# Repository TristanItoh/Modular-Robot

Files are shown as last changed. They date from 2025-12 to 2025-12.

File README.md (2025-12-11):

# Wireless Snap-On Modular Robot
A wheeled robot with a module slot on the front, allowing module attachments wirelessly through pogo pins. Driven by two motors in the rear and controlled by a joystick mounted on top.

## Why?
I've previously made a robot that is sort of modular, but you need to connect the wires together and use the janky pins to attach them to the base. I wanted to create a new robot with an improved system completely wireless.

## PCB: 
Includes:
- Power management
- Motor driver
- Wireless module interface (pogo pins)
- Microcontroller hub
- Headlights module
  


### Schematic


## CAD: 
Smooth, round base with a flat front for module additions. Detachable lid for battery and PCB.






Simple shell for the headlights module to be contained in.



Simple lightweight wheels with slots for motor shaft.



<br>

## BOM
| Item | Type | Quantity | Price (Total) | Vendor |
|:---|:---|---:|:---|:---|
| CL21A106KAYNNNE | 10uF | 10 | $0.10 | JLCPCB |
| CL31A226KAHNNNE | 22uF | 5 | $0.20 | JLCPCB |
| CL21B105KBFNNNE | 1uF | 5 | $0.04 | JLCPCB |
| CL10A225KO8NNNC | 2.2uF | 10 | $0.05 | JLCPCB |
| CL31A107MQHNNNE | 100uF | 5 | $0.27 | JLCPCB |
| CL05B104KO5NNNC | 100nF | 20 | $0.02 | JLCPCB |
| CL21B103KBANNNC | 10nF | 5 | $0.03 | JLCPCB |
| B2B-XH-A(LF)(SN) | JSTConnector | 20 | $0.70 | LCSC |
| XL-302UWC | XL-302UWC | 20 | $0.46 | LCSC |
| KT-0603R | KT-0603R | 5 | $0.03 | JLCPCB |
| AO3401A | AO3401A | 5 | $0.28 | JLCPCB |
| 0603WAF5101T5E | 5.1kΩ | 10 | $0.01 | JLCPCB |
| 0603WAF1201T5E | 1.2kΩ | 5 | $0.01 | JLCPCB |
| 0603WAF3303T5E | 330kΩ | 5 | $0.01 | JLCPCB |
| 1206W4F1003T5E | 100kΩ | 5 | $0.02 | JLCPCB |
| 0805W8F1002T5E | 10kΩ | 20 | $0.04 | JLCPCB |
| 0805W8F1000T5E | 100Ω | 10 | $0.02 | JLCPCB |
| 0805W8F2200T5E | 220Ω | 15 | $0.03 | JLCPCB |
| TS-1088-AR02016 | TS-1088-AR02016 | 15 | $0.64 | JLCPCB |
| ESP32-S3-WROOM-1-N8R2 | 2.4GHz | 0 | $4.69 | LCSC |
| TP4056 | TP4056 | 0 | $0.42 | LCSC |
| TPS61202DRCT | TPS61202DRCT | 0 | $1.76 | LCSC |
| APH0420T4R7M | 4.7uH | 0 | $0.41 | LCSC |
| AP2112K-3.3TRG1 | AP2112K-3.3TRG1 | 0 | $0.46 | LCSC |
| DRV8833PWPR | DRV8833PWPR | 0 | $0.67 | LCSC |
| TYPE-C 16PIN 2MD(073) | TYPE-C16PIN2MD(073) | 10 | $0.59 | LCSC |
| 1206L150/16NR | 1206L150/16NR | 10 | $0.46 | LCSC |
| Xinyangze YZ134112062B-02 | Pogo pins | 5 | $1.43 | LCSC |
| Joystick module | nan | 1 | 1.2 | Aliexpress |
| Gear motor | N20 | 10 | 7 | Aliexpress |
| PCB + PCBA + other fees | nan | nan | $14.86 | JLCPCB |
| Shipping and handling | nan | nan | $11.62 | LCSC |
| Shipping | nan | nan | $1.99 | Aliexpress |

Total: $50.50

[Sheet With Links](https://docs.google.com/spreadsheets/d/1DUcNddXo8VYgS7BtmotNU0K7JUAEApslePg6cg7R3zo/edit?usp=sharing)

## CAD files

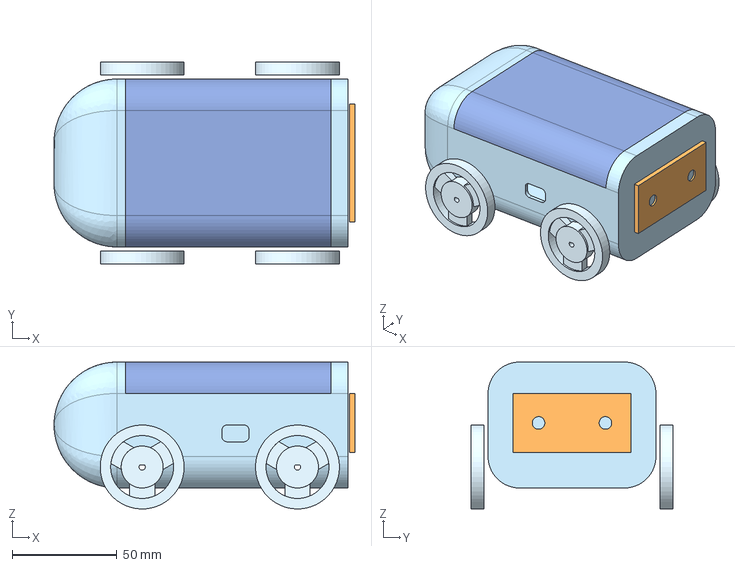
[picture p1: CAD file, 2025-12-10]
CAD/Full robot.step
143.4 x 96.0 x 70.0 mm

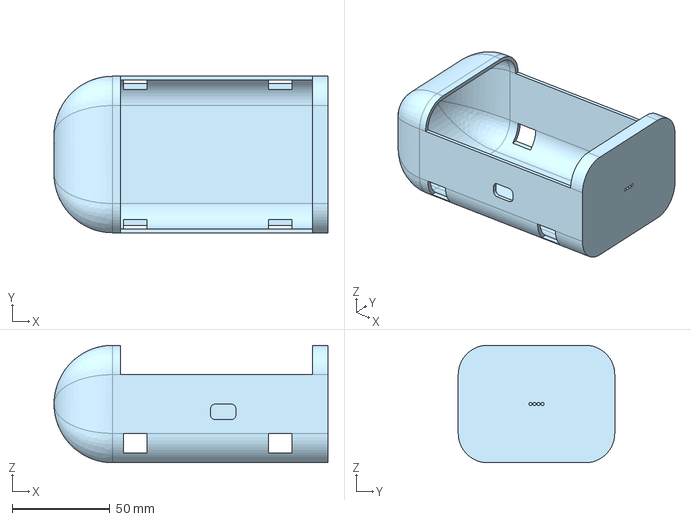
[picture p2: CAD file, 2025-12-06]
CAD/Body.step
140.0 x 80.0 x 60.0 mm

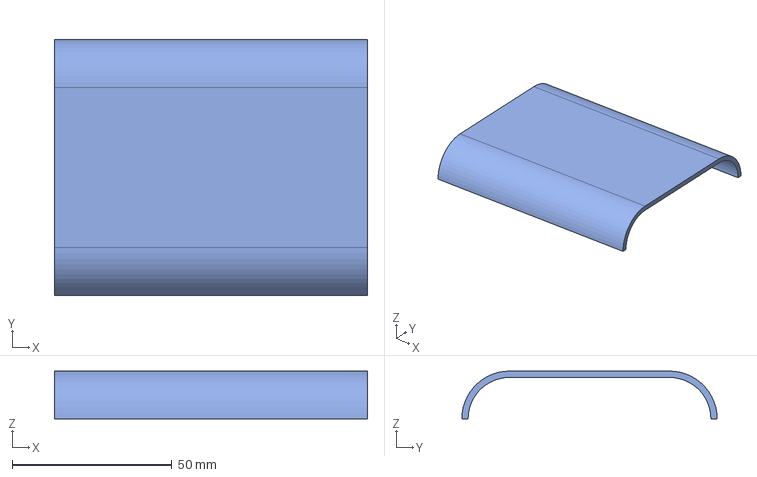
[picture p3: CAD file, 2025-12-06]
CAD/Body Lid.step
98.0 x 80.0 x 15.0 mm

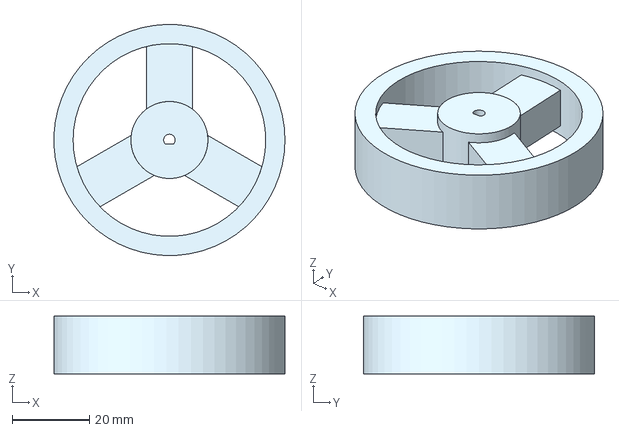
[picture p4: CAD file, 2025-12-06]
CAD/Wheel.step
60.0 x 60.0 x 15.0 mm

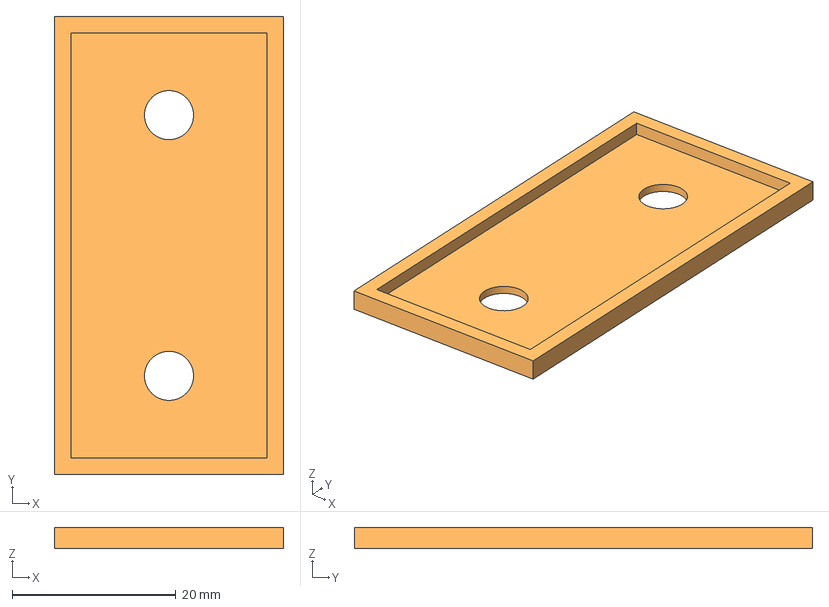
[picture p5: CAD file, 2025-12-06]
CAD/Headlights Body.step
28.0 x 56.0 x 2.60 mm

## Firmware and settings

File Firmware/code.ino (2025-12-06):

/*
 * ESP32-S3 Modular Robot Base Firmware
 * 
 * Hardware:
 * - ESP32-S3 WROOM module
 * - DRV8833 dual motor driver
 * - Analog joystick (X, Y, SW)
 * - Headlight module (LED control via GPIO)
 * - 3 buttons: RESET, BOOT, USER
 * - Status LED
 * 
 * Controls:
 * - Joystick X/Y: Tank-style motor control
 * - Joystick button press: Toggle headlights
 * - User button: Emergency motor stop
 */

// ===== PIN DEFINITIONS =====

// Motor Driver (DRV8833)
#define MOTOR_AIN1  6   // Left motor direction 1
#define MOTOR_AIN2  7   // Left motor direction 2
#define MOTOR_BIN1  15  // Right motor direction 1
#define MOTOR_BIN2  16  // Right motor direction 2

// PWM channels for motor control
#define PWM_FREQ    20000  // 20kHz PWM frequency
#define PWM_RES     8      // 8-bit resolution (0-255)
#define PWM_CH_A1   0
#define PWM_CH_A2   1
#define PWM_CH_B1   2
#define PWM_CH_B2   3

// Headlight Module (Pogo Pin)
#define LED_CTRL    5   // Headlight control GPIO
#define EXTRA_GPIO  4   // Extra GPIO (unused)

// Joystick (analog + button)
#define JOY_X       1   // ADC pin for X-axis (GPIO1)
#define JOY_Y       2   // ADC pin for Y-axis (GPIO2)
#define JOY_SW      21  // Joystick button (shared with USER button)

// Buttons
#define BTN_USER    21  // User button / Joystick SW
#define BTN_BOOT    0   // Boot button (GPIO0)

// Status LED
#define STATUS_LED  48  // Status indicator LED

// ===== GLOBAL VARIABLES =====

bool headlightsOn = false;
bool motorsEnabled = true;
unsigned long lastButtonPress = 0;
const unsigned long debounceDelay = 200; // ms

// Joystick center calibration
int joyXCenter = 2048;  // ADC center value (12-bit: 0-4095)
int joyYCenter = 2048;
const int deadzone = 300; // Joystick deadzone

// ===== SETUP =====

void setup() {
  Serial.begin(115200);
  delay(100);
  Serial.println("\n=== ESP32-S3 Robot Starting ===");
  
  // Configure motor pins with PWM
  setupMotors();
  
  // Configure GPIO pins
  pinMode(LED_CTRL, OUTPUT);
  pinMode(EXTRA_GPIO, OUTPUT);
  pinMode(STATUS_LED, OUTPUT);
  pinMode(BTN_USER, INPUT_PULLUP);
  pinMode(BTN_BOOT, INPUT_PULLUP);
  
  // Configure ADC for joystick
  analogReadResolution(12); // 12-bit ADC (0-4095)
  analogSetAttenuation(ADC_11db); // Full range 0-3.3V
  
  // Initial states
  digitalWrite(LED_CTRL, LOW);
  digitalWrite(STATUS_LED, HIGH); // Power on indicator
  
  // Calibrate joystick center
  calibrateJoystick();
  
  // Startup blink
  for(int i = 0; i < 3; i++) {
    digitalWrite(STATUS_LED, LOW);
    delay(100);
    digitalWrite(STATUS_LED, HIGH);
    delay(100);
  }
  
  Serial.println("Robot initialized!");
  Serial.println("Joystick controls motors, press button for headlights");
}

// ===== MAIN LOOP =====

void loop() {
  // Read joystick position
  int joyX = analogRead(JOY_X);
  int joyY = analogRead(JOY_Y);
  
  // Read buttons
  bool btnPressed = (digitalRead(BTN_USER) == LOW);
  bool bootPressed = (digitalRead(BTN_BOOT) == LOW);
  
  // Handle button press (toggle headlights)
  if(btnPressed && (millis() - lastButtonPress > debounceDelay)) {
    toggleHeadlights();
    lastButtonPress = millis();
  }
  
  // BOOT button = emergency stop
  if(bootPressed) {
    motorsEnabled = false;
    stopMotors();
    blinkStatusLED();
  } else {
    motorsEnabled = true;
  }
  
  // Process joystick and control motors
  if(motorsEnabled) {
    controlMotors(joyX, joyY);
  }
  
  // Status LED heartbeat (slow blink when running)
  static unsigned long lastBlink = 0;
  if(millis() - lastBlink > 1000) {
    digitalWrite(STATUS_LED, !digitalRead(STATUS_LED));
    lastBlink = millis();
  }
  
  delay(20); // 50Hz control loop
}

// ===== MOTOR CONTROL FUNCTIONS =====

void setupMotors() {
  // Configure PWM channels for each motor pin
  ledcSetup(PWM_CH_A1, PWM_FREQ, PWM_RES);
  ledcSetup(PWM_CH_A2, PWM_FREQ, PWM_RES);
  ledcSetup(PWM_CH_B1, PWM_FREQ, PWM_RES);
  ledcSetup(PWM_CH_B2, PWM_FREQ, PWM_RES);
  
  // Attach pins to PWM channels
  ledcAttachPin(MOTOR_AIN1, PWM_CH_A1);
  ledcAttachPin(MOTOR_AIN2, PWM_CH_A2);
  ledcAttachPin(MOTOR_BIN1, PWM_CH_B1);
  ledcAttachPin(MOTOR_BIN2, PWM_CH_B2);
  
  stopMotors();
}

void controlMotors(int joyX, int joyY) {
  // Convert joystick to motor speeds (tank drive)
  // Y-axis = forward/backward
  // X-axis = left/right turning
  
  int forward = map(joyY, 0, 4095, -255, 255);
  int turn = map(joyX, 0, 4095, -255, 255);
  
  // Apply center offset
  forward = forward - map(joyYCenter, 0, 4095, -255, 255);
  turn = turn - map(joyXCenter, 0, 4095, -255, 255);
  
  // Apply deadzone
  if(abs(forward) < map(deadzone, 0, 4095, 0, 255)) forward = 0;
  if(abs(turn) < map(deadzone, 0, 4095, 0, 255)) turn = 0;
  
  // Calculate left and right motor speeds (tank drive mixing)
  int leftSpeed = constrain(forward + turn, -255, 255);
  int rightSpeed = constrain(forward - turn, -255, 255);
  
  // Drive motors
  setMotorA(leftSpeed);
  setMotorB(rightSpeed);
  
  // Debug output (optional - comment out for performance)
  static unsigned long lastPrint = 0;
  if(millis() - lastPrint > 500) {
    Serial.printf("Joy X:%d Y:%d | Fwd:%d Turn:%d | L:%d R:%d\n", 
                  joyX, joyY, forward, turn, leftSpeed, rightSpeed);
    lastPrint = millis();
  }
}

void setMotorA(int speed) {
  // Motor A (left) control
  if(speed > 0) {
    // Forward
    ledcWrite(PWM_CH_A1, speed);
    ledcWrite(PWM_CH_A2, 0);
  } else if(speed < 0) {
    // Reverse
    ledcWrite(PWM_CH_A1, 0);
    ledcWrite(PWM_CH_A2, -speed);
  } else {
    // Brake
    ledcWrite(PWM_CH_A1, 0);
    ledcWrite(PWM_CH_A2, 0);
  }
}

void setMotorB(int speed) {
  // Motor B (right) control
  if(speed > 0) {
    // Forward
    ledcWrite(PWM_CH_B1, speed);
    ledcWrite(PWM_CH_B2, 0);
  } else if(speed < 0) {
    // Reverse
    ledcWrite(PWM_CH_B1, 0);
    ledcWrite(PWM_CH_B2, -speed);
  } else {
    // Brake
    ledcWrite(PWM_CH_B1, 0);
    ledcWrite(PWM_CH_B2, 0);
  }
}

void stopMotors() {
  ledcWrite(PWM_CH_A1, 0);
  ledcWrite(PWM_CH_A2, 0);
  ledcWrite(PWM_CH_B1, 0);
  ledcWrite(PWM_CH_B2, 0);
}

// ===== HEADLIGHT CONTROL =====

void toggleHeadlights() {
  headlightsOn = !headlightsOn;
  digitalWrite(LED_CTRL, headlightsOn ? HIGH : LOW);
  
  Serial.print("Headlights: ");
  Serial.println(headlightsOn ? "ON" : "OFF");
  
  // Quick status LED flash to confirm
  digitalWrite(STATUS_LED, LOW);
  delay(50);
  digitalWrite(STATUS_LED, HIGH);
}

// ===== UTILITY FUNCTIONS =====

void calibrateJoystick() {
  Serial.println("Calibrating joystick center...");
  delay(500);
  
  // Sample center position multiple times
  long sumX = 0, sumY = 0;
  for(int i = 0; i < 10; i++) {
    sumX += analogRead(JOY_X);
    sumY += analogRead(JOY_Y);
    delay(10);
  }
  
  joyXCenter = sumX / 10;
  joyYCenter = sumY / 10;
  
  Serial.printf("Joystick center: X=%d, Y=%d\n", joyXCenter, joyYCenter);
}

void blinkStatusLED() {
  // Fast blink for error/stop
  for(int i = 0; i < 5; i++) {
    digitalWrite(STATUS_LED, LOW);
    delay(50);
    digitalWrite(STATUS_LED, HIGH);
    delay(50);
  }
}

// ===== OPTIONAL: Battery Monitoring (if you add voltage divider) =====
/*
#define VBAT_PIN 3  // ADC pin for battery voltage
#define VBAT_DIVIDER 2.0  // Voltage divider ratio

float readBatteryVoltage() {
  int raw = analogRead(VBAT_PIN);
  float voltage = (raw / 4095.0) * 3.3 * VBAT_DIVIDER;
  return voltage;
}

void checkBattery() {
  float vbat = readBatteryVoltage();
  if(vbat < 3.3) {
    // Low battery warning
    Serial.println("WARNING: Low battery!");
    // Blink LED rapidly
  }
}
*/
